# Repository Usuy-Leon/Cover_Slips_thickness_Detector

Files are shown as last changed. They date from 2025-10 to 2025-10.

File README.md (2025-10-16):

<div align="center">
<div style="background-color: #1a1b1e; padding: 20px; border-radius: 8px; margin-bottom: 20px;">

# Shinya-blades: Cover_Slips_thickness_Detector

>“Small changes in cover glass thickness or refractive index produce a disproportionately large optical path error, reducing image contrast and resolution.”
>
>— Inoué, S, Video Microscopy, 2nd ed., Plenum Press (1997)

</div>
<div align="left">
 
This gadget is like a tiny playground for cover slips, featuring two razor-thin steel blades acting as barriers, with a shim creating a precise offset. When you drop a cover slip into the gap,  Geometry happens and makes the cover slip to tilt depending on its thickness. Even Hair thin differences in thickness become easy-to-read 
</div>
<div align="center">

Screencast From 2025-10-09 21-00-33

</div>
<hr>
<div align="left">

# Why does it matter?
Cover-slip thickness is critically important in microscopy because high-resolution optical systems are designed for specific optical path lengths between the specimen and the objective lens. Even small deviations from that ideal thickness can cause spherical aberration, loss of contrast, and degraded resolution.

Yes, professional manufacturers nowadays do a decent job of reporting cover-slip thickness correctly (Types 0 to 2). However, not all producers follow these standards, so having a tool like this can be really useful especially when working with objectives designed for specimens very close to the cover slip (corrected for 0.17 mm thickness). If you happen to use a cover slip that’s too thick, you could accidentally scratch your very expensive objective in an irreversible way.

<div align="center">
 
Screencast From 2025-10-09 21-04-59

</div>
 
# The Microscopist: Shinya Inoue 

<div align="center">

>“In fluorescence, phase-contrast, or quantitative polarization microscopy, consistent optical path length ensures reproducible intensity and retardation measurements”
>
>— Inoué, S., Collected Works, Article 4: Cover-Slip Thickness Gauge (1951)
</div>

 Shinya Inoué built his cover-slip thickness gauge (1951): to quickly select slips within ±0.005 mm of 0.17 mm. (Check the paper atached in files).

<div align="center">

>
</div>
 
In 1950, while teaching cell biology at Princeton University, Shinya Inoué realized that commercial “#1.5” cover slips, however, often varied by several micrometers. Measuring each one with a micrometer was slow and risked contamination, so Inoué devised a simple mechanical gauge in 1951.

His device used two razor blades set at a fixed angle: the cover slip itself acted as a tiny lever, tilting according to its thickness. A scale converted that tilt into a direct reading in millimeters fast, clean, and accurate to a few microns.

Remarkably, the same gauge built more than 70 years ago was still in use in Inoué’s laboratory half a century later a small but elegant example of his ingenuity in combining optical precision with practical design.

# 3D Version: thickness Detector

This is a tribute to the great Shinya Inoue, but also a 3D STL file designed to be used for microscopy enthusiast and professionals. 

Screencast From 2025-10-09 21-03-19
</div>
<div align="center">
 
# Inovation

The modern 3D-printed version of Inoué’s coverSlip thickness gauge preserves his elegant simplicity while embracing digital fabrication. Inspired by traditional Japanese joinery (kigumi) the craft of creating strong, precise wooden joints without screws or nails this design uses interlocking parts that snap together with perfect alignment. The results a timeless scientific tool reimagined with the precision and accessibility of modern 3D printing.

[CoverSlip_Gauge_BluePrints.pdf](https://github.com/user-attachments/files/22936184/CoverSlip_Gauge_BluePrints.pdf)

</div>
<div align="left">
 
# Assembly Guide
##  Required Materials

| Quantity | Item | Notes |
|---|---|---|
| 2 | **M2 × 12 mm screws** | Pan-head or socket-head |
| 2 | **M2 nuts** | Nylock nuts preferred for secure hold |
| 2 | **Razor blades** | Standard stainless steel, single or double edge |
---

#  Assembly Steps

### 1. Clean and Prepare Parts
- Remove all printing supports and debris.   

### 2. Join the Base and Back Plate
- Align the **base plate** and **back plate** using the interlocking **kigumi joints**.  
- Press them together firmly until they fit flush and tight.  
- This Japanese joinery system ensures perfect alignment without glue or extra hardware.  

### 3. Place the Blades
- Lay the **two razor blades** flat on the **shim area** of the back plate, on both sides of the central recess.  
- The sharp edges should face inward, toward the small central gap where the cover slip will rest.  
- Handle blades carefully 

### 4. Attach the Blade Holders
- Position the **two orange blade-holder plates** over the blades.  
- Their **tapered tips** should meet neatly at the recess, forming a precise “tweezer-like” edge.  

### 5. Insert and Tighten Screws
- Ensure all holes are clear and smooth — test-fit one M2 screw to confirm easy passage. 
- Insert the **2 M2 screws** through the holes in the blade holders and back plate.  
- Secure each with an **M2 nut** on the opposite side.  
- Tighten the screws evenly — firm enough to clamp the blades securely, but not so tight that plastic parts deform.  

### 6. Final Check
- Inspect the alignment: both blade tips should be parallel and evenly spaced around the recess.  
- **The distance between them MUST BE 0.17 mm.**  

### Enjoy

# Want to improve it?

The OpenScad code file is open source well written and clear, find it and make it yours !

# Recomended Readings:

Shillaber, C. P. (1944). Photomicrography in Theory and Practice. Wiley.

Inoué, S., & Spring, K. R. (1997). Video Microscopy. Plenum Press.

Inoué, S. (1951). Cover-Slip Thickness Gauge. In Collected Works of Shinya Inoué.

Pawley, J. B. (Ed.) (2006). Handbook of Biological Confocal Microscopy. Springer.

Born & Wolf (1999). Principles of Optics. Cambridge Univ. Press — for spherical aberration derivation.

</div>

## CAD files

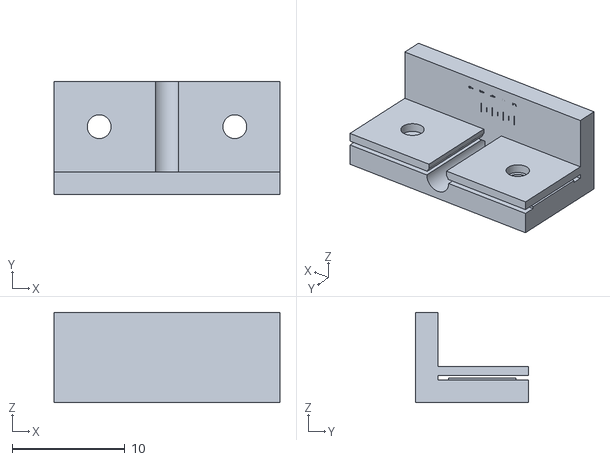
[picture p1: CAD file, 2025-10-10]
CoverSlip_Gauge/Full_Assembly.stl
20.0 x 10.0 x 8.00

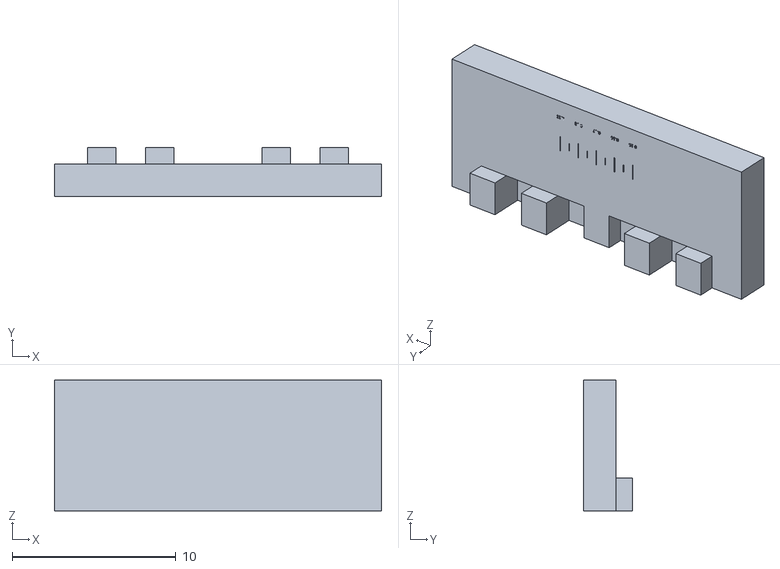
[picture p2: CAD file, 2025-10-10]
CoverSlip_Gauge/Base.stl
20.0 x 3.00 x 8.00

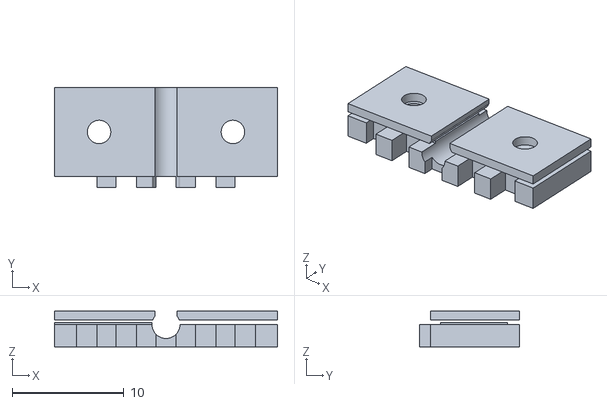
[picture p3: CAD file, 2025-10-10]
CoverSlip_Gauge/Back.stl
20.0 x 9.00 x 3.20

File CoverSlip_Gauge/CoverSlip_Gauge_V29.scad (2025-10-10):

// COVER-SLIP THICKNESS GAUGE — Back Plate v29
/* 
                             COVER-SLIP THICKNESS GAUGE — Back Plate v29
                    
   Dark Field Filters v29

A device to messure CoverSlips in an easy and reliable way

This 3D file is designed to be for microscopy enthusiast and professionals.
     
Source :https://github.com/Usuy-Leon/CoverSlip_Gauge
Inspired on the beutifull work of Shinya Inoue

This project is an Open Source project,
by Usuy D. Leon, 2025.10.26
Microscopist, National University of Colombia, Bogota DC,

    */
// 
// =======================================================================

part = "assembly";  // "base", "back", or "assembly"
show_debug = true;  
$fn = 120;

// ---------------- GLOBAL PARAMETERS ----------------
base_x = 20; base_y = 8; base_z = 2;
back_h = 8; back_thick = base_z; clearance = 0.05;  // tight fit

// Joinery
edge_margin = 2;
joint_pairs = 5;
finger_h = base_z / 2;
available_width = base_x - 2 * edge_margin;
n_segments = 2 * joint_pairs - 1;
seg_w = available_width / n_segments;
male_w = seg_w - clearance;
cavity_w = seg_w + clearance;

// Shim
shim_thick = 0.20;
shim_length = (base_x - 2) / 2;
shim_z = base_z + back_h / 2 - shim_thick / 2;
shim_y = base_y - back_thick - shim_thick;

// Coverslip recess
recess_w = 2;
recess_h = 8;
recess_depth = 1;
recess_x = (base_x - recess_w) / 2;
recess_z = base_z + (back_h - recess_h) / 3;

// Blade-holding plates (one on each side of recess)
blade_thick = 0.8;       
blade_gap = 0.2;         
blade_height = back_h;  
blade_y_front = shim_y - blade_gap - blade_thick;

// Left and right blade-holder x dimensions
blade_left_x = 0;
blade_right_x = recess_x + recess_w;
blade_left_len = recess_x;                 
blade_right_len = base_x - (recess_x + recess_w);

// Tweezer tip taper (thinning near the recess)
taper_len = 1.5;        // how far the taper goes inward
taper_thin = 0;       // final thickness at the inner edge

// M2 screw holes (2 per side)
m2_diam = 2.1; // clearance for M2 screws
m2_rad = m2_diam / 2;
hole_offset_x1 = 4;
hole_offset_x2 = 16;
hole_offset_z = base_z + back_h / 2; // centered vertically
hole_positions = [
    [hole_offset_x1, hole_offset_z],
    [hole_offset_x2, hole_offset_z]
];

// Precision scale (0.15–0.20)
start_value = 0.15;
end_value   = 0.19;
major_step  = 0.01;
minor_step  = 0.005;
scale_length = 5.0;
tick_depth  = 0.35;
tick_long   = 0.9;
tick_short  = 0.45;
font_size   = 0.2;
font_depth  = 0.3;
text_v_gap  = 1.1;
scale_center_x = (base_x) / 2;
scale_center_y = base_y / 3;

// ---- Helper: format exactly two decimals ----
function fmt2(x) =
    let(v = round(x * 100))
    str(floor(v / 100), ".", (v % 100 < 10 ? "0" : ""), v % 100);

// =======================================================================
// BASE PLATE
// =======================================================================
module base_plate() {
    difference() {
        color("silver") cube([base_x, base_y, base_z]);

        // joinery cavities (odd segments)
        for (seg = [0 : n_segments - 1]) {
            if (seg % 2 == 1) {
                seg_x = edge_margin + seg * seg_w;
                cx = seg_x - (cavity_w - seg_w) / 2;
                translate([cx, base_y - base_z, base_z - finger_h])
                    cube([cavity_w, base_z, finger_h + 0.02]);
            }
        }

        // tick + label engraving
        total_minor = floor((end_value - start_value) / minor_step + 0.001);
        total_major = floor((end_value - start_value) / major_step + 0.001);
        spacing = scale_length / total_minor;
        scale_start = scale_center_x - (scale_length / 2);

        for (i = [0 : total_minor]) {
            x_tick = scale_start + i * spacing;
            tick_len = (i % 2 == 0) ? tick_long : tick_short;
            translate([x_tick, scale_center_y - tick_len / 2, base_z - tick_depth])
                cube([0.04, tick_len, tick_depth]);
        }

        for (k = [0 : total_major]) {
            val = start_value + k * major_step;
            label = fmt2(val);
            x_num = scale_start + (k * (major_step / minor_step)) * spacing;
            translate([x_num, scale_center_y - tick_long / 2 - text_v_gap, base_z - font_depth])
                linear_extrude(height = font_depth)
                    text(label, size = font_size, halign = "center", valign = "top");
        }
    }

    // male joinery teeth (even segments, skip center)
    for (seg = [0 : n_segments - 1]) {
        if (seg % 2 == 0 && seg != floor(n_segments / 2)) {
            seg_x = edge_margin + seg * seg_w;
            mx = seg_x + (seg_w - male_w) / 2;
            translate([mx, base_y - base_z, base_z])
                color([0.78, 0.62, 0.4])
                cube([male_w, base_z, finger_h]);
        }
    }
}

// =======================================================================
// BACK PLATE
// =======================================================================
module tapered_plate(x_pos, y_pos, length, color_name) {
    color(color_name)
    hull() {
        translate([x_pos, y_pos, base_z]) cube([length, blade_thick, blade_height]);
        translate([x_pos + length - taper_len, y_pos, base_z]) cube([taper_len, taper_thin, blade_height]);
    }
}

module back_plate() {
    difference() {
        union() {
            // Main wall
            color("lightblue")
                translate([0, base_y - back_thick, base_z])
                    cube([base_x, back_thick, back_h]);

            // Shim I decided to duion it to the structure, color to debugg
            if (show_debug)
                color("magenta")
                    translate([0, shim_y, shim_z - 3])
                        cube([shim_length, shim_thick, 6]);
            else
                color("deepskyblue")
                    translate([0, shim_y, base_z + back_h - shim_thick])
                        cube([shim_length, shim_thick, shim_thick]);

            // Downward Kigumi teeth (odd segments)
            for (seg = [0 : n_segments - 1]) {
                if (seg % 2 == 1) {
                    seg_x = edge_margin + seg * seg_w;
                    tx = seg_x + (seg_w - male_w) / 2;
                    translate([tx, base_y - back_thick, base_z - finger_h])
                        color([0.72, 0.55, 0.4])
                            cube([male_w, back_thick, finger_h]);
                }
            }

            // Blade holder plates 
            tapered_plate(blade_left_x, blade_y_front, blade_left_len, "orange");
            tapered_plate(blade_right_x, blade_y_front, blade_right_len, "orange");
        }

        // Cavities for even segments (fit base)
        for (seg = [0 : n_segments - 1]) {
            if (seg % 2 == 0 && seg != floor(n_segments / 2)) {
                seg_x = edge_margin + seg * seg_w;
                cx = seg_x - (cavity_w - seg_w) / 2;
                translate([cx, base_y - back_thick - 0.01, base_z])
                    cube([cavity_w, back_thick + 0.02, finger_h + 0.02]);
            }
        }

        // Central recess for coverslip
        translate([recess_x+1, base_y - back_thick - 0.001, recess_z])
            cylinder(h=20, r=1.25, center=true);

        // M2 screw holes through both blade holders + back plate 
        for (p = hole_positions) {
            x_h = p[0];
            z_h = p[1];
            // Centered through both blade holders and back plate
            y_center = blade_y_front + blade_thick / 2 + (shim_thick + blade_gap * 2 + back_thick) / 2;
            total_depth = blade_thick * 2 + shim_thick + blade_gap * 2 + back_thick + 0.4;
            translate([x_h, y_center, z_h])
                rotate([90, 0, 0])
                    color("black")
                    cylinder(h = total_depth, r = m2_rad, center = true);
        }
    }
}

// =======================================================================
// Others ......................
// =======================================================================
module assembly() {
    rotate([-90, 0, 0]) {
        base_plate();
        back_plate();
    }
}

if (part == "base") {
    rotate([-90, 0, 0]) base_plate();
} else if (part == "back") {
    rotate([-90, 0, 0]) back_plate();
} else {
    assembly();
}
